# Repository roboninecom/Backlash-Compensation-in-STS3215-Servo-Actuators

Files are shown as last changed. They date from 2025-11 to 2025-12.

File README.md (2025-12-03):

# Backlash Compensation in STS3215 Servo Actuators

This repository contains the source code, data analysis scripts, and LaTeX source for the research paper **"Backlash Compensation in STS3215 Servo Actuators"**.

The project demonstrates a practical method to eliminate mechanical backlash in low-cost Feetech STS3215 servos using a dual-motor configuration with controlled pretension.

---

## 📂 Project Structure

```text
├── cad/                         # Hardware design files (.step and .stl)
├── logs/                        # Output directory for telemetry data (CSV)
├── paper/                       # LaTeX source code of the article and figures
├── software/
│   ├── backlash_test/
│   │   ├── .env                     # Environment variables
│   │   ├── .gitignore               # Git ignore rules
│   │   ├── app.js                   # Main Node.js controller application
│   │   ├── config.js                # Serial port configuration
│   │   ├── package.json             # Node.js dependencies and scripts
│   │   ├── sweepConfig.js           # Configuration for motion sequences
│   │   └── TelemetryLogger.js       # Module for CSV data logging
│   ├── logs_analysis/
│   │   ├── config/                  # Example config files
│   │   ├── log_calc.py              # Calculates backlash statistics based on provided CSV log file
│   |   ├── log_viz.py               # Generates visualisation from provided CSV log file
│   |   ├── config_utils.py          # Some common utilities used by analysis and visualisation scripts
```

## 🛠 Hardware Requirements

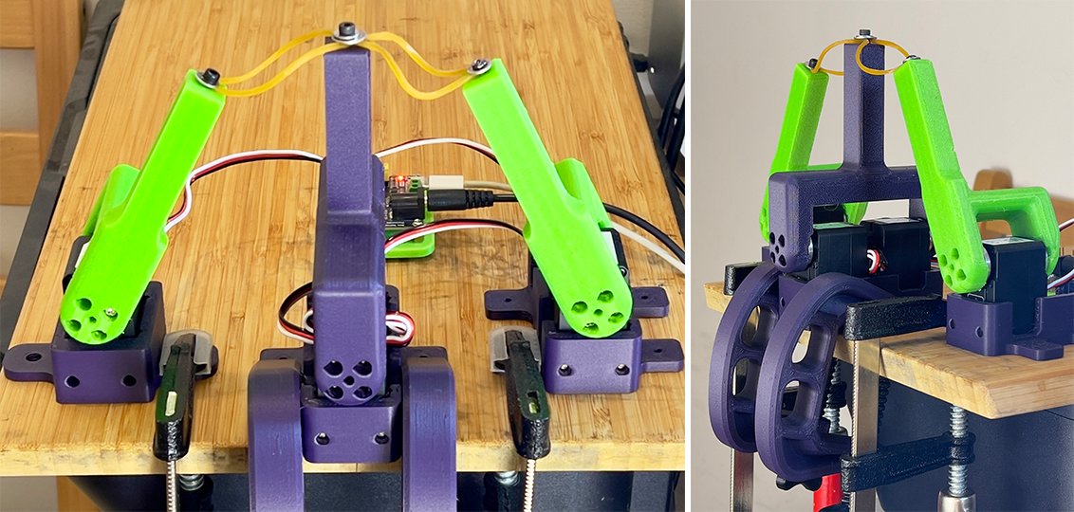
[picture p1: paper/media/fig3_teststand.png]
Test Stand Setup

*Figure: Mechanical test stand used for backlash measurements.*

To reproduce the experiments, you will need:
*   **Servos:** 2x Feetech STS3215 (configured in dual-mode) + additional servos for load testing.
*   **Controller:** USB-TTL Adapter (e.g., Feetech URT-1) connected to a PC.
*   **Power Supply:** 12V DC power supply capable of at least 3A.
*   **Mechanical Assembly:** Dual-servo bracket (see paper for details).

## 🚀 Getting Started

### 1. Controller Setup (Node.js)

The Node.js application manages the servos, executes motion profiles, and logs telemetry.

**Prerequisites:** Node.js (v14+), NPM.

```bash
cd software/backlash_test

# Install dependencies
npm install

# Configure environment variables
# Create a .env file or set these manually
export SERIAL_PORT=COM3           # Or /dev/ttyUSB0 on Linux/Mac
export SERIAL_BAUD_RATE=1000000
```

**Running the Experiment:**

To start the control loop and logging:

```bash
node app.js
```

*   Configuration for motion patterns and servo IDs is located in `sweepConfig.js`.
*   Logs are automatically saved to the `logs/` directory.

### 2. Motor analysis utilities

**Prerequisites:** Python 3.8+, pandas, matplotlib, numpy.

`log_calc.py` handles motor-analysis scenario by reading a JSON configuration that describes which motors define the analysis phase window, which motors should be reported, and the stretched/relaxed targets for the actuated motors. 

Run the script by passing the config and the log CSV:

```bash
python logs_analysis/log_calc.py logs_analysis/config/config_m1_m2.json /path/to/log.csv
```

`log_viz.py` uses the exact same config files to decide which motors to plot (from `report_motor_ids`) and which actuators provide the relaxed/stretched overlays. Invoke it the same way:

```bash
python logs_analysis/log_viz.py logs_analysis/config/config_m1_m2.json  /path/to/log.csv
```

## 📄 Research Paper

The full text of the research paper is located in the `paper/` directory.
You can compile it using any standard LaTeX distribution (TeX Live, MiKTeX) or online editor (Overleaf).

## 👥 Author Information

**Boris Kotov**
*   Senior Software Engineer, Robotics Control Systems.
*   Email: [hello@robonine.com](mailto:hello@robonine.com)

**Company: Robonine**
*   Developing accessible robotic solutions for education and research.
*   Website: [robonine.com](https://robonine.com)

## 📜 License

This project and the associated paper are distributed under the **Creative Commons Attribution 4.0 International License (CC BY 4.0)**.
You are free to share and adapt the material as long as appropriate credit is given.

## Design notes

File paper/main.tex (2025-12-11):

\documentclass[11pt,a4paper]{article}

\usepackage[margin=1in]{geometry}
\usepackage{graphicx}
\usepackage{amsmath,amssymb}
\usepackage{siunitx}
\sisetup{per-mode=symbol}
\usepackage{booktabs}
\usepackage{hyperref}
\usepackage{xurl}
\usepackage{caption}
\usepackage{placeins}

\title{Backlash Compensation in STS3215 Servo Actuators}
\author{Boris Kotov\\
Robonine\\
\texttt{boris.k@robonine.com}\\
\url{https://robonine.com}}
\date{}

\begin{document}
\maketitle

\begin{abstract}
This work presents a practical backlash compensation method for Feetech STS3215 servo actuators using a dual-motor configuration with controlled pretension. Experimental results show a reduction of effective output backlash from 14.78 encoder counts (approximately \SI{1.30}{\degree}) to 1--2 counts (approximately \SIrange{0.09}{0.18}{\degree}), approaching encoder resolution limits. The method does not require mechanical modification and maintains approximately \SI{80}{\percent} of total torque capacity. The technique is suitable for low-cost robotics and educational motion control systems.
\end{abstract}

\noindent\textbf{Keywords:} servo actuators, backlash compensation, dual motor drive, robotics, low-cost motion control

\vspace{0.5em}
\noindent\textbf{License.} This paper is distributed under the terms of the Creative Commons Attribution 4.0 International License (CC BY 4.0).

\section{Introduction}

The Feetech STS3215 servo has become popular in hobbyist and educational robotics due to its low cost, satisfactory torque output, integrated closed-loop controller, and straightforward serial interface. These characteristics make it attractive for student projects, DIY robotic arms, small mobile manipulators, pan--tilt units, gimbal mechanisms, and general-purpose articulated prototypes where inexpensive but reasonably precise actuation is needed. In such contexts, the STS3215 offers an accessible platform for experimenting with kinematics, feedback control, and embedded motion systems without the cost barriers of industrial-grade actuators.

Despite these advantages, the actuator exhibits several limitations. Because of its multi-stage gear train, total mechanical backlash is significant: measurements indicate approximately \SIrange{0.8}{0.9}{\degree} of rotational free play, corresponding to roughly \SI{1.3}{\milli\meter} of motion at a \SI{100}{\milli\meter} lever arm. This level of lost motion degrades positioning accuracy, complicates bidirectional tracking, and limits the usability of the servos in applications requiring precise reversals or high-fidelity control.

The goal of this study is to evaluate simple, implementable methods for reducing the functional impact of backlash when using a paired configuration of STS3215 servos. The work focuses on practical compensation strategies suitable for low-cost robotic systems, with the aim of improving motion accuracy without hardware modification.

\section{STS3215 Main Features}

\subsection{Hardware Specifications}

The main hardware specifications of the STS3215 servo are summarized in Table~\ref{tab:specs}.

\begin{table}[ht]
    \centering
    \caption{STS3215 main hardware specifications.}
    \label{tab:specs}
    \begin{tabular}{ll}
        \toprule
        Specification & Value \\
        \midrule
        Operating (nominal) voltage & \SI{12}{\volt} (operating range \SIrange{4}{14}{\volt}) \\
        Rated torque & \SI{10}{\kilo\gram\centi\meter} @ \SI{12}{\volt} \\
        Stall (peak) torque & \SI{30}{\kilo\gram\centi\meter} @ \SI{12}{\volt} \\
        Encoder resolution & 12-bit magnetic encoder: 4096 steps over \SI{360}{\degree} \\
        Gear type & Metal gearbox; steel gears and ball bearings \\
        Gear ratio & 1\,:\,345 reduction (12~V, 30~kg\,cm version) \\
        \bottomrule
    \end{tabular}
\end{table}

\subsection{Communication Architecture}

The STS3215 uses a half-duplex TTL serial bus, allowing multiple servos to share the same communication line. Servos can be daisy-chained by connecting their signal ports in series. All communication uses the manufacturer's digital packet protocol, which supports variable-length instruction and status frames.

The communication protocol supports synchronized actuation of multiple servos on the same bus. Through broadcast or group commands, several servos can receive and execute target updates simultaneously. This capability is essential for coordinated motion, such as paired joint actuation, dual-motor couplings, or experimental setups where timing symmetry between actuators directly affects performance.

\subsection{Device Identification and Memory}

Each servo contains a unique ID stored in EEPROM. EEPROM parameters are non-volatile and remain stored after power cycles. RAM parameters (e.g., present position, speed, voltage) reset at each boot.

\subsection{Main Control Modes}

The internal controller supports several operating modes:
\begin{enumerate}
    \item \textbf{Position control mode:} target position specified in encoder units; configurable speed and acceleration; supports continuous update of the goal position for trajectory tracking.
    \item \textbf{Continuous rotation / speed mode:} servo behaves like a motor with speed command, useful for wheels and drive systems.
\end{enumerate}

\subsection{Adjustable Parameters}

The internal controller exposes a set of parameters that influence performance and safety:
\begin{itemize}
    \item PID gains (proportional, integral, derivative), which shape servo stiffness, tracking accuracy, and damping.
    \item Deadband width around the target position; reducing the deadband increases accuracy but may increase oscillation.
    \item Speed and acceleration limits, including soft-start ramps to prevent overshoot and reduce gear stress.
    \item Protection options: over-voltage, under-voltage, over-temperature shutdown, over-current/overload protection, torque limit.
    \item Range and calibration settings: mechanical limits, angle offsets, and zero-position calibration using encoder feedback.
\end{itemize}

\subsection{Feedback and Status Reporting}

The servo provides live telemetry including present position (encoder units), speed, load estimate (proportional to current), supply voltage, temperature, and error flags (overload, overheating, voltage error, etc.).

\section{Backlash Compensation with Two Opposed STS3215 Servos}

\subsection{Mechanical Arrangement}

Two STS3215 servos are mounted back-to-back with their output shafts facing opposite directions. The shafts are mechanically coupled using the standard 25T servo horns (the small stock circular output disks) and a 3D-printed bridging clamp bracket secured with four screws into the horns. This rigid connection ensures accurate shaft alignment and minimizes relative motion between the servos during operation. The two servos are fixed together on a common mounting plate, maintaining their relative orientation and spacing.

\begin{figure}[ht]
    \centering
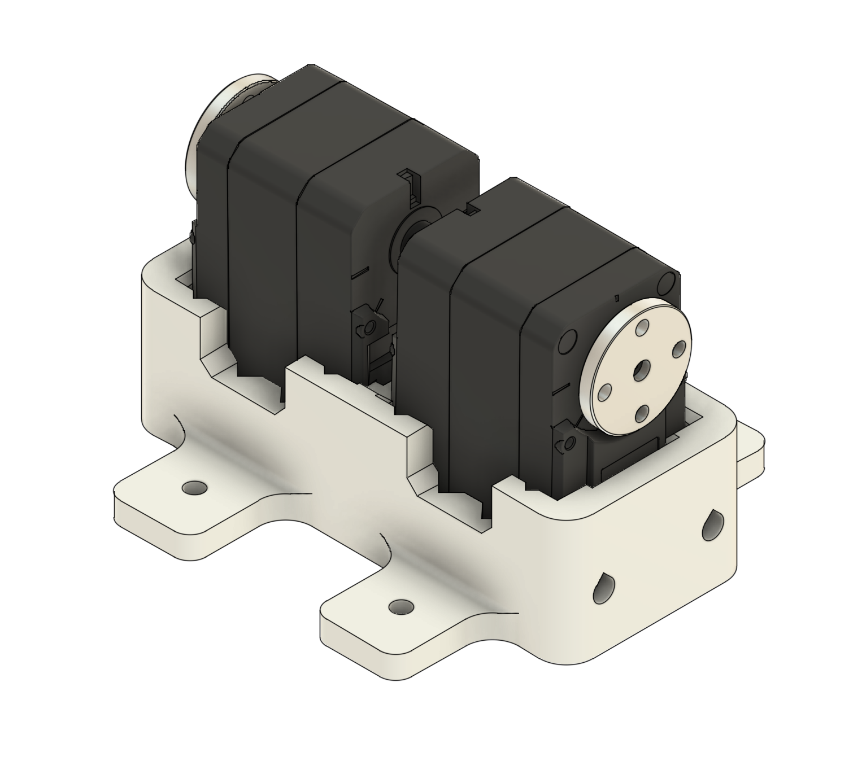
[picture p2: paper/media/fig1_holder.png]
    
    \caption{Two STS3215 servos mounted in the holder.}
    \label{fig:holder}
\end{figure}

\begin{figure}[ht]
    \centering
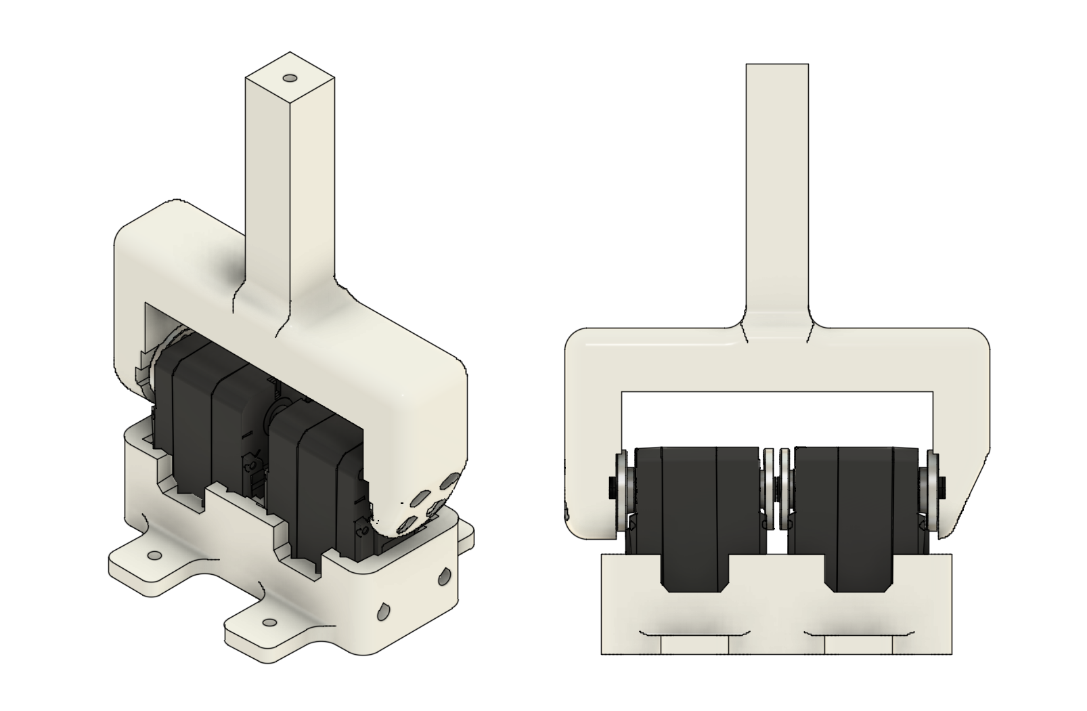
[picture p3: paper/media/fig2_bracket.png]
    
    \caption{Two STS3215 servos with attached test bracket and lever.}
    \label{fig:bracket}
\end{figure}

\subsection{Control Strategy}

Each STS3215 has finite gearbox backlash. When a single motor is commanded to change direction, the output shaft can move a small amount with minimal restoring torque as the gear teeth transition between flanks. By coupling two motors and biasing them in opposite directions, each motor keeps its gear train loaded on a different flank. The two dead zones no longer overlap, so the combined system exhibits near-zero play around the commanded angle.

We create that bias by giving the two motors slightly different home positions (a small position offset). At steady state, each motor holds a small position error, producing a steady pretension torque in opposite directions. In this work, the pretension is set to approximately \SI{3}{\percent} of stall torque---enough to take up the slack, but small enough to keep current and heat modest.

\subsection{Simple Model}

Let each motor have a backlash half-width $b$ (in encoder counts), so a single motor has an effective deadzone
\[
[-b, +b].
\]
Inside this zone, small changes of commanded position $u$ produce negligible output torque $T$:
\[
u \in [-b, b] \;\Rightarrow\; T \approx 0.
\]

When two motors are rigidly coupled and we apply an offset $d$ (counts) between their commanded angles, the steady-state torques $T_1$ and $T_2$ pull in opposite directions. If the magnitude of the offset is larger than the effective deadband,
\[
|d| > b_{\mathrm{eff}},
\]
where $b_{\mathrm{eff}}$ includes the controller deadband and mechanical play, both gear trains remain seated on opposite flanks. The combined closed-loop stiffness around the setpoint becomes approximately the sum of the individual stiffnesses, and the apparent deadzone collapses.

A practical rule from this setup is to choose $|d|$ slightly greater than the deadband but small enough that the resulting holding current remains modest. In our tests, an offset $d$ corresponding to roughly \SI{3}{\percent} of stall torque (about \SI{0.9}{\kilo\gram\centi\meter} for a \SI{30}{\kilo\gram\centi\meter} servo) worked well. On a \SI{100}{\milli\meter} lever, this torque corresponds to approximately \SI{0.09}{\kilo\gram force} at the tip (about \SI{0.88}{\newton}), which is enough to seat the gears without stressing the motor.

\subsection{Implementation Steps}

\begin{enumerate}
    \item Zero both motors mechanically (lever centered), with no offsets.
    \item Preload one flank: gently rotate the lever clockwise and set Motor~1's home position.
    \item Preload the opposite flank: gently rotate counter-clockwise and set Motor~2's home/offset so that Motor~2 pushes the other way.
    \item Verify current draw at rest and during small dithers; trim the offsets to target approximately \SI{3}{\percent} stall torque (or another chosen limit).
\end{enumerate}

\section{Test Setup and Limitations}

\subsection{Encoder Placement and Backlash Measurement}

The STS3215 incorporates its magnetic encoder after the gearbox, directly on the output shaft. This architecture simplifies control but introduces a measurement constraint: the encoder cannot observe motion within the internal gear stages. As a result, true internal backlash cannot be directly measured, because the internal PID loop continuously attempts to drive the shaft to the commanded position.

Within the default deadband range, however, the controller does not correct small deviations, allowing the output shaft to move freely inside the mechanical slack. This characteristic enables an indirect measurement method. When torque is enabled and a small external force is applied to the output lever, the encoder reading changes even though the controller remains within its deadband. Knowing the encoder resolution, these small deviations can be converted into angular displacement, providing an estimate of effective backlash.

\subsection{Test Stand}

A simple mechanical test stand was constructed to evaluate backlash and the effectiveness of compensation methods. The setup consists of:
\begin{enumerate}
    \item \textbf{Primary test motor(s):} one or two STS3215 servos serving as the unit under test. A rigid \SI{100}{\milli\meter} lever is mounted to the output shaft to amplify measurable motion.
    \item \textbf{Opposing actuation motors:} two additional STS3215 units, each equipped with its own lever, are mounted opposite the primary lever. These ``puller'' motors apply controlled forces in clockwise and counter-clockwise directions to displace the primary shaft within its backlash zone.
\end{enumerate}

\begin{figure}[ht]
    \centering
    
    \caption{Mechanical test stand used for backlash measurements.}
    \label{fig:teststand}
\end{figure}

\subsection{Opposing-Load Mechanism (Elastic Bands)}

To apply a controlled, repeatable counter-torque without introducing extra drivetrain backlash, the two opposing motors pull the main \SI{100}{\milli\meter} lever via elastic bands. The bands are pre-tensioned so that the measured pull at the lever tip is approximately \SI{0.3}{\kilo\gram force}.

The resulting torque at the lever tip is
\[
\tau \approx 0.3~\text{kgf} \times 0.1~\text{m} \approx \SI{0.294}{\newton\meter} \approx \SI{3.0}{\kilo\gram\centi\meter},
\]
which is about \SI{10}{\percent} of stall torque (\SI{30}{\kilo\gram\centi\meter}) and \SI{30}{\percent} of rated torque (\SI{10}{\kilo\gram\centi\meter}) for a single STS3215 at \SI{12}{\volt}. This is high enough to fully seat the gear train in either direction, yet low enough to avoid saturating the internal controller.

The elastic coupling provides a compliant, backlash-free load path, so backlash in the two opposing motors can be ignored. It also smooths load reversals, reducing shock and motor current spikes during the back-and-forth sequence.

\begin{figure}[ht]
    \centering
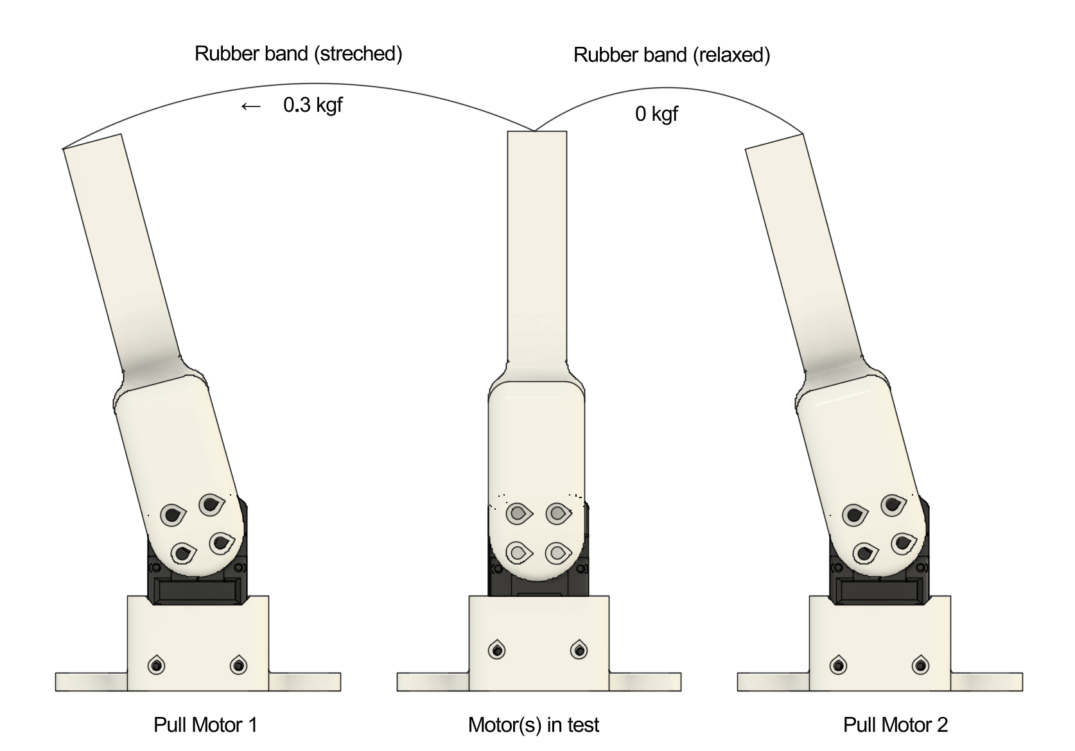
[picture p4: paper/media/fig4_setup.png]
    
    \caption{Example test setup. The center motor holds position while the left puller motor applies approximately \SI{0.3}{\kilo\gram force} to the lever. The right puller motor is relaxed and does not apply force.}
    \label{fig:setup}
\end{figure}

\subsection{Force Application Sequence}

The primary motor executes a short back-and-forth movement to preload its internal gears in either the clockwise or counter-clockwise direction. Once loaded, the opposing motors alternately pull the lever in opposite directions. Between pulls, they briefly release tension to ensure that no residual force biases the measurement. The entire sequence---preload motions, alternating pulls, and release intervals---is coordinated by custom control code running on the host controller.

\begin{figure}[ht]
    \centering
    
    \caption{Test sequence, stage~1 (preparation). Both elastic bands are relaxed. The tested motor(s) move in CW or CCW direction and return to the center position, preloading the gears.}
    \label{fig:sequence1}
\end{figure}

\begin{figure}[ht]
    \centering
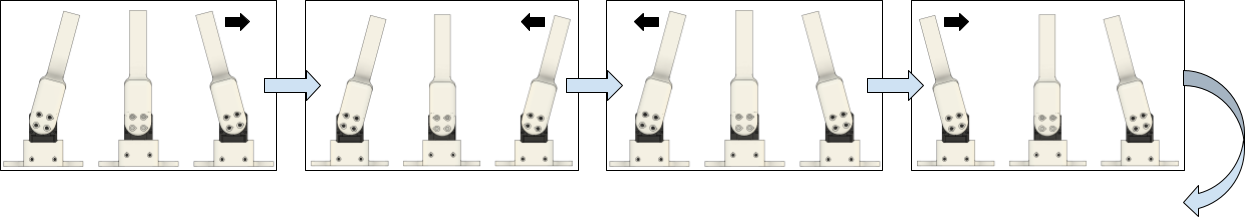
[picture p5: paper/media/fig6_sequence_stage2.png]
    
    \caption{Test sequence, stage~2 (stress). The lever of the tested motor(s) remains in the central position while the pull motors alternately apply load in opposite directions. Between pulls, both elastic bands are relaxed.}
    \label{fig:sequence2}
\end{figure}

\subsection{Telemetry Acquisition}

All servos stream periodic status data to the host, where custom logging software collects and stores it in CSV format for later analysis. Logged parameters include:
\begin{itemize}
    \item timestamp,
    \item present and target positions,
    \item load/torque estimate and current consumption.
\end{itemize}
A Python post-processing script visualizes the motion profiles and computes effective backlash by analyzing position deviations caused by the alternating external forces.

\subsection{Limitations}

Several limitations should be noted:
\begin{itemize}
    \item Because the encoder is placed after the gearbox, only output backlash can be observed; internal gear-stage behavior remains unmeasured.
    \item The internal PID deadband interacts with the measurement method: too small a deadband causes the controller to fight the applied force, whereas too large a deadband reduces measurement resolution. The default deadband setting is used here.
    \item Over the small displacements used for backlash probing, elastic band force change is minimal but not zero, introducing a small nonlinearity.
\end{itemize}

\section{Results and Analysis}

\subsection{Quantities and Conversions}

With a 12-bit encoder, one revolution corresponds to 4096 counts, so one count is
\[
\Delta \theta = \frac{360^\circ}{4096} \approx 0.0879^\circ.
\]
At a radius of \SI{100}{\milli\meter}, the corresponding linear displacement per count is
\[
\Delta x \approx 0.0879^\circ \times \frac{\pi}{180^\circ} \times 100~\text{mm} \approx \SI{0.153}{\milli\meter}.
\]

\subsection{Backlash Measurement Procedure}

As part of each test, a sequence of motions is executed according to the force application sequence described above. During this sequence, motor telemetry (including each servo current position and target position) is sampled at approximately \SI{10}{\hertz} rate. For each cycle, two reference conditions are extracted:
\begin{itemize}
    \item \textbf{Loaded reference:} the actual encoder position while the pull motors apply a nominal \SI{0.3}{\kilo\gram force} to the lever in one direction.
    \item \textbf{Unloaded reference:} the actual encoder position immediately after both pull motors have relaxed and no external force is applied to the main lever.
\end{itemize}

For each pull direction (CW and CCW), two reference points are extracted from the telemetry stream:
\begin{itemize}
    \item \textbf{Unloaded (relaxed) state:} the actual encoder position immediately after both pull motors release tension.
    \item \textbf{Loaded (stretched) state:} the actual encoder position while the approximately \SI{0.3}{\kilo\gram force} is applied in that direction.
\end{itemize}

For each of these states, multiple samples are collected over the repeated motion cycles. The samples are averaged to obtain stable estimates of:
\begin{itemize}
    \item $p_{\mathrm{cw,unloaded}}$
    \item $p_{\mathrm{ccw,unloaded}}$
    \item $p_{\mathrm{cw,loaded}}$
    \item $p_{\mathrm{ccw,loaded}}$
\end{itemize}

The total positional deviation between the two pull directions is then computed separately for the unloaded and loaded conditions:
\begin{align}
d_{\mathrm{unloaded}} &= \bigl| p_{\mathrm{cw,unloaded}} - p_{\mathrm{ccw,unloaded}} \bigr|, \\
d_{\mathrm{loaded}} &= \bigl| p_{\mathrm{cw,loaded}} - p_{\mathrm{ccw,loaded}} \bigr|.
\end{align}

These two values represent the measured backlash in the absence of external force and under the applied counter-torque, respectively. Since the motion sequence is repeated multiple times, a sufficient number of samples is collected to compute the average backlash and its dispersion for each configuration (single motor, dual motor, dual motor with preload).

\subsection{Single STS3215 Servo with Default Settings}

Before evaluating dual-motor compensation methods, the backlash of a single STS3215 servo was measured to establish a baseline. The motor was mounted rigidly, driven to a fixed target position (2047 counts), and subjected to the standard force-application sequence.

\begin{figure}[ht]
    \centering
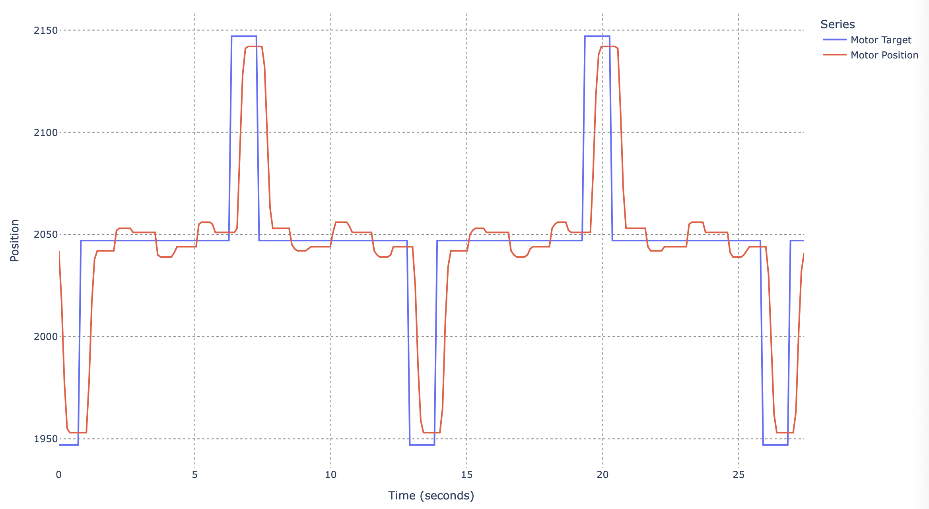
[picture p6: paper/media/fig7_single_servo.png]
    
    \caption{Test results for a single STS3215 servo with default settings under alternating external load.}
    \label{fig:single}
\end{figure}

For the single STS3215, the measured position deviation between CW and CCW loading was:
\begin{itemize}
    \item Loaded state: 14.78 counts,
    \item Unloaded (relaxed) state: 7.03 counts.
\end{itemize}
These correspond to:
\begin{itemize}
    \item Loaded backlash: $\approx \SI{1.30}{\degree}$ or $\approx \SI{2.27}{\milli\meter}$ at \SI{100}{\milli\meter} radius,
    \item Unloaded backlash: $\approx \SI{0.62}{\degree}$ or $\approx \SI{1.08}{\milli\meter}$ at \SI{100}{\milli\meter} radius.
\end{itemize}
These results confirm that a single STS3215 exhibits on the order of 1--2~mm of effective backlash at a \SI{100}{\milli\meter} lever radius, increasing under load.

\subsection{Coupled STS3215 Servos with Default Settings}

To evaluate the effect of mechanically coupling two STS3215 servos, the motors were first tested in a rigid back-to-back configuration without applying any positional offset or deliberate pretension. Both actuators were commanded to the same target position and driven synchronously, sharing a common output through the fixed bracket assembly.

\begin{figure}[ht]
    \centering
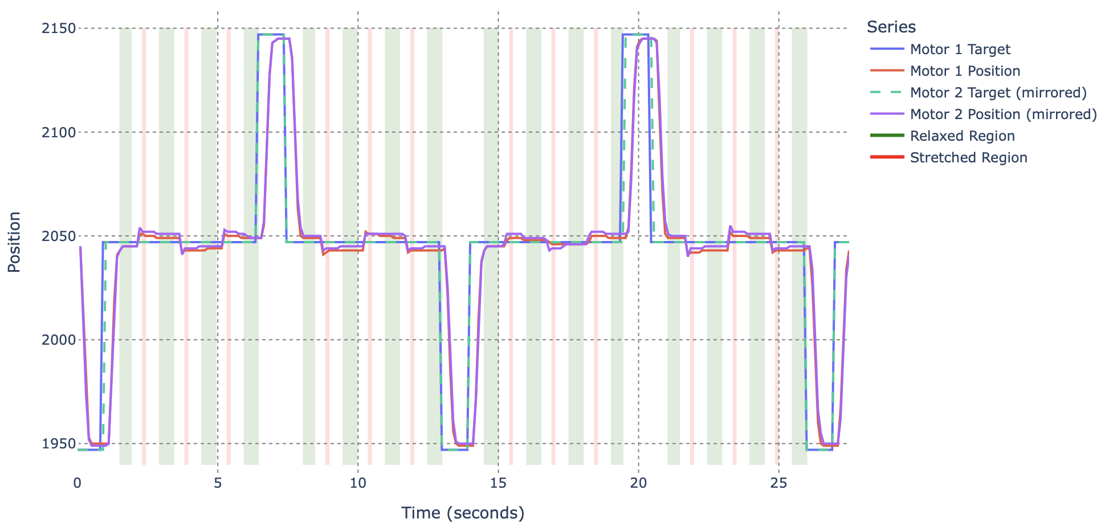
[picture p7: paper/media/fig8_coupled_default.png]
    
    \caption{Test results for two coupled STS3215 servos with default settings. Highlighted regions indicate intervals with relaxed and stretched elastic bands. Red and blue curves denote measured positions of Servo~1 and Servo~2; the dashed line shows the commanded target position.}
    \label{fig:coupled_default}
\end{figure}

With two STS3215 servos rigidly coupled and commanded to the same target position, the effective backlash is reduced compared to a single actuator. From the averaged data, the total position deviation between CW and CCW loading is:

\textbf{Loaded} (approximately \SI{3}{\kilo\gram\centi\meter}):
\begin{itemize}
    \item Servo~1: 7.50 counts $\approx \SI{0.66}{\degree} \approx \SI{1.15}{\milli\meter}$ at \SI{100}{\milli\meter} radius,
    \item Servo~2: 8.00 counts $\approx \SI{0.70}{\degree} \approx \SI{1.23}{\milli\meter}$ at \SI{100}{\milli\meter} radius.
\end{itemize}

\textbf{Unloaded:}
\begin{itemize}
    \item Servo~1: 6.00 counts $\approx \SI{0.53}{\degree} \approx \SI{0.92}{\milli\meter}$,
    \item Servo~2: 6.00 counts $\approx \SI{0.53}{\degree} \approx \SI{0.92}{\milli\meter}$.
\end{itemize}

Simply coupling two STS3215s back-to-back approximately halves the loaded backlash compared to the single-motor case, even before applying explicit compensation.

\subsection{Coupled STS3215 Servos with Home Position Offset}

To further reduce residual backlash, a controlled home-position offset was introduced between the two coupled STS3215 units. The lever assembly was manually rotated to preload the gear train of one motor in the CW direction, and this position was stored as its home reference. The lever was then rotated in the opposite direction to preload the second motor in CCW, and its home position was recorded accordingly. This procedure establishes a small, constant pretension torque between the servos, ensuring that both gear trains remain seated on opposite flanks.

\begin{figure}[ht]
    \centering
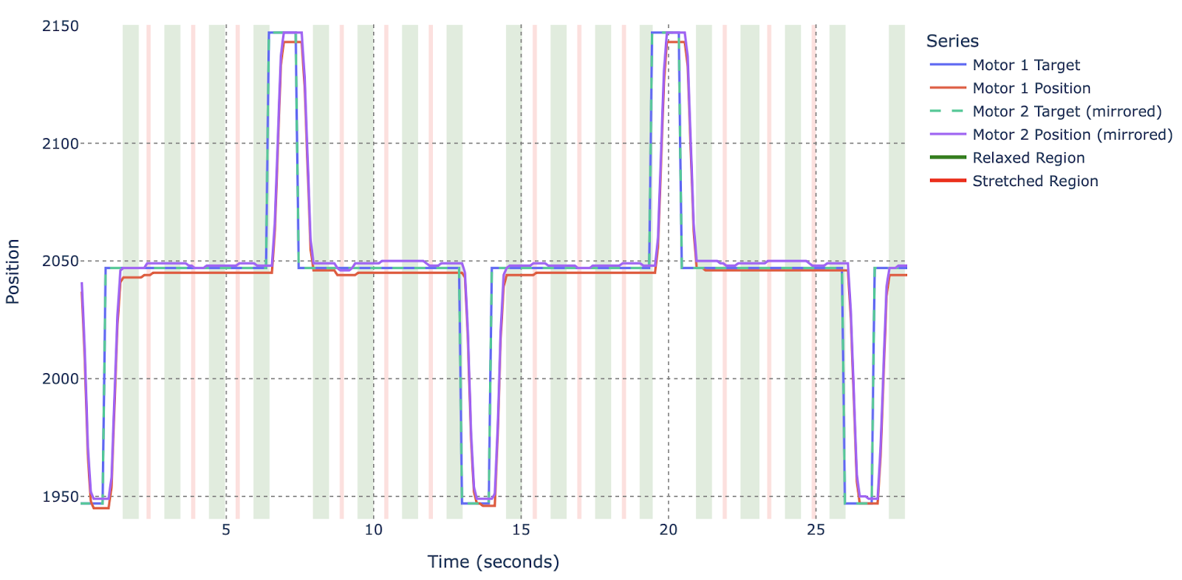
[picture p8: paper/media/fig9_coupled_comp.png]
    
    \caption{Test results for two coupled STS3215 servos with backlash compensation via home-position offset. Red and blue curves denote Servo~1 and Servo~2; the dashed line shows the commanded position. Highlighted regions indicate relaxed and stretched load intervals.}
    \label{fig:coupled_comp}
\end{figure}

\begin{figure}[ht]
    \centering
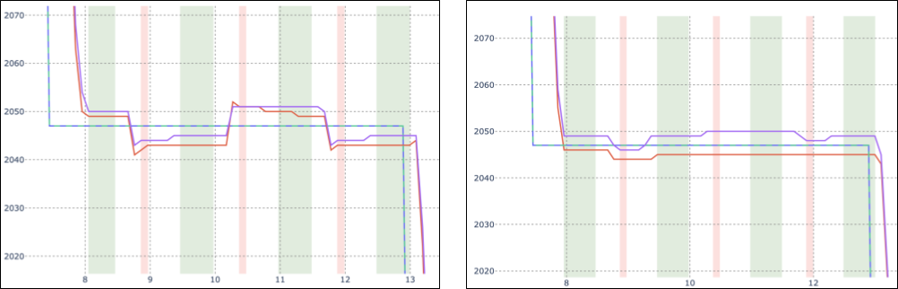
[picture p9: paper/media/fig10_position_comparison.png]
    
    \caption{Position deviation comparison for coupled servos. Left: configuration with default settings (no compensation). Right: configuration with home-position offset providing pretension.}
    \label{fig:comparison}
\end{figure}

With the home-position offset (pretension) applied, the measured position deviation is:

\textbf{Loaded} (approximately \SI{3}{\kilo\gram\centi\meter}):
\begin{itemize}
    \item Servo~1: 0 counts,
    \item Servo~2: 2 counts $\approx \SI{0.18}{\degree} \approx \SI{0.31}{\milli\meter}$ at \SI{100}{\milli\meter} radius.
\end{itemize}

\textbf{Unloaded:}
\begin{itemize}
    \item Servo~1: 0 counts,
    \item Servo~2: 1 count $\approx \SI{0.088}{\degree} \approx \SI{0.15}{\milli\meter}$ at \SI{100}{\milli\meter} radius.
\end{itemize}

With a small home-position offset that preloads the two servos against opposite gear flanks, the apparent backlash is reduced to 1--2 encoder counts, i.e., on the order of the encoder's own resolution (approximately \SIrange{0.09}{0.18}{\degree}, \SIrange{0.15}{0.31}{\milli\meter} at \SI{100}{\milli\meter} radius). This is a very significant improvement over the single-motor case and a clear improvement over the uncompensated dual-motor configuration.

\FloatBarrier

\subsection{Results Summary}

To enable direct comparison among all test configurations, backlash values for both loaded (L) and unloaded (U) conditions were compiled into a single results table. For dual-motor setups, the larger (worst-case) deviation between the two servos is used to represent system backlash.

\begin{table}[ht]
    \centering
    \caption{Combined backlash test results. U: unloaded (measured immediately after both pulling motors relax). L: loaded (measured while the \SI{0.3}{\kilo\gram force} counter-force is applied). Backlash is expressed in encoder counts, angular displacement, and linear displacement at a \SI{100}{\milli\meter} radius. For two-motor setups, the larger of the two measured deviations is reported.}
    \label{tab:backlash}
    \begin{tabular}{lccc}
        \toprule
        Configuration & Backlash (counts) & Backlash (deg) & Backlash (mm) \\
        \midrule
        Single motor (U) & 7.03 & 0.62 & 1.07 \\
        Single motor (L) & 14.78 & 1.30 & 2.26 \\
        Coupled, no compensation (U) & 6.00 & 0.53 & 0.92 \\
        Coupled, no compensation (L) & 8.00 & 0.70 & 1.22 \\
        Coupled, offset compensation (U) & 1.00 & 0.09 & 0.15 \\
        Coupled, offset compensation (L) & 2.00 & 0.18 & 0.31 \\
        \bottomrule
    \end{tabular}
\end{table}

\FloatBarrier

\section{Conclusions}

The experiments confirm that mechanical backlash in STS3215 servos can be effectively minimized through a dual-actuator configuration. By coupling two motors and introducing a small positional offset, both gear trains remain preloaded against opposite flanks, effectively eliminating the free-motion zone. The resulting system maintains approximately \SI{80}{\percent} of the combined torque capacity of both servos, indicating only minor efficiency losses while achieving near-zero measurable backlash.

Thermal monitoring showed no overheating or abnormal current draw, suggesting that the applied pretension remains within safe limits for continuous operation. This simple, low-cost compensation method significantly improves positioning accuracy and rigidity using standard hobby-grade components, making it well suited for robotics studies, educational applications, and precision motion experiments.

\section{Future Work}

Future work may include dynamic backlash compensation, where the pretension or position offset is adjusted in real time based on torque feedback or direction of motion. It would also be valuable to study the influence of mechanical coupling stiffness, including bracket material and geometry, on system behavior.

Additional tests with different servo models, gear ratios, and control tunings could help generalize the method and quantify its limits in higher-load or high-speed applications.

\section*{Appendix: Code and Supplementary Materials}

Custom control code for the dual-servo compensation system, mechanical design files (CAD models), test stand schematics, and post-processing scripts are available at:

\noindent GitHub repository: \url{https://github.com/roboninecom/Measuring-Backlash-in-Popular-UART-Servos}

\section*{Author Information}

\textbf{Boris Kotov} is a senior software engineer specializing in robotics control systems and embedded programming for autonomous platforms.

\textbf{Robonine} is a company focused on developing accessible robotic solutions for education and research (\url{https://robonine.com}).

\nocite{*}
\bibliographystyle{ieeetr}
\bibliography{references}

\end{document}

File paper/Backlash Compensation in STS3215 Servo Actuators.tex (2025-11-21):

\documentclass[11pt,a4paper]{article}

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

\title{Backlash Compensation in STS3215 Servo Actuators}
\author{Boris Kotov\\
Robonine\\
\texttt{hello@robonine.com}\\
\url{https://robonine.com}}
\date{}

\begin{document}
\maketitle

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

\noindent\textbf{Keywords:} servo actuators, backlash compensation, dual motor drive, robotics, low-cost motion control

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

\section{Introduction}

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

\section{STS3215 Main Features}

\subsection{Hardware Specifications}

The main hardware specifications of the STS3215 servo are summarized in Table~\ref{tab:specs}.

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

\subsection{Communication Architecture}

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

\subsection{Device Identification and Memory}

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

\subsection{Main Control Modes}

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

\subsection{Adjustable Parameters}

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

\subsection{Feedback and Status Reporting}

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

\section{Backlash Compensation with Two Opposed STS3215 Servos}

\subsection{Mechanical Arrangement}

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

\subsection{Control Strategy}

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

\subsection{Simple Model}

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

\subsection{Implementation Steps}

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

\section{Test Setup and Limitations}

\subsection{Encoder Placement and Backlash Measurement}

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

\subsection{Test Stand}

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

\subsection{Opposing-Load Mechanism (Elastic Bands)}

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

\subsection{Force Application Sequence}

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

\subsection{Telemetry Acquisition}

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

\subsection{Limitations}

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

\section{Results and Analysis}

\subsection{Quantities and Conversions}

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

\subsection{Backlash Measurement Procedure}

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

\subsection{Single STS3215 Servo with Default Settings}

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

\subsection{Coupled STS3215 Servos with Default Settings}

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

\subsection{Coupled STS3215 Servos with Home Position Offset}

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

With the home-position offset (pretension) applied, the measured position deviation is:

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

\subsection{Results Summary}

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

\section{Conclusions}

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

\section{Future Work}

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

\section*{Appendix: Code and Supplementary Materials}

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

\noindent GitHub repository: \url{https://github.com/roboninecom/Backlash-Compensation-in-STS3215-Servo-Actuators}

\section*{Author Information}

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

\begin{thebibliography}{9}

\bibitem{feetech_manual}
Feetech Automatic Technology Co., Ltd., ``STS3215 Serial Bus Servo User Manual,'' 2023. Available at \url{https://wiki.feetech.com/en/wiki/STS3215} (accessed: 20 Nov. 2025).

\bibitem{tao_backlash}
G.~Tao and P.~V.~Kokotovic, ``Adaptive Control of Systems with Backlash,'' \emph{Automatica}, vol.~29, no.~2, pp.~323--335, 1993, doi:~10.1016/0005-1098(93)90126-E.

\bibitem{nordin_survey}
M.~Nordin and P.~O.~Gutman, ``Controlling Mechanical Systems with Backlash---A Survey,'' \emph{Automatica}, vol.~38, no.~10, pp.~1633--1649, 2002, doi:~10.1016/S0005-1098(02)00047-X.

\bibitem{chandrasekar_measurement}
S.~Chandrasekar and K.~Srinivasan, ``Inferential Based Measurement of Backlash in Servo System,'' \emph{International Journal of Mechanical Sciences}, vol.~175, p.~105505, 2020, doi:~10.1016/j.ijmecsci.2020.105505.

\bibitem{hou_dual_motor}
L.~Hou, Y.~Cao, X.~Li, M.~Gao, and S.~Wang, ``Backlash Elimination Control for Robotic Joints with Dual-Motor Drive,'' \emph{Actuators}, vol.~13, no.~8, p.~291, 2024, doi:~10.3390/act13080291.

\bibitem{tan_precision}
J.~Tan, N.~Zhang, Y.~Zhao, and Z.~Wang, ``Nonlinear Robust Adaptive Precision Motion Control of Motor Servo Systems with Unknown Actuator Backlash Compensation,'' \emph{ISA Transactions}, vol.~138, pp.~237--251, 2023, doi:~10.1016/j.isatra.2023.02.022.

\bibitem{zhou_deadzone}
L.~Zhou, Z.~Mao, and J.~Huang, ``Robust Stabilization of Nonlinear Uncertain Plants with Backlash or Dead Zone in the Actuator,'' \emph{IEEE Transactions on Control Systems Technology}, vol.~10, no.~2, pp.~158--166, 2002, doi:~10.1109/87.987060.

\end{thebibliography}

\end{document}

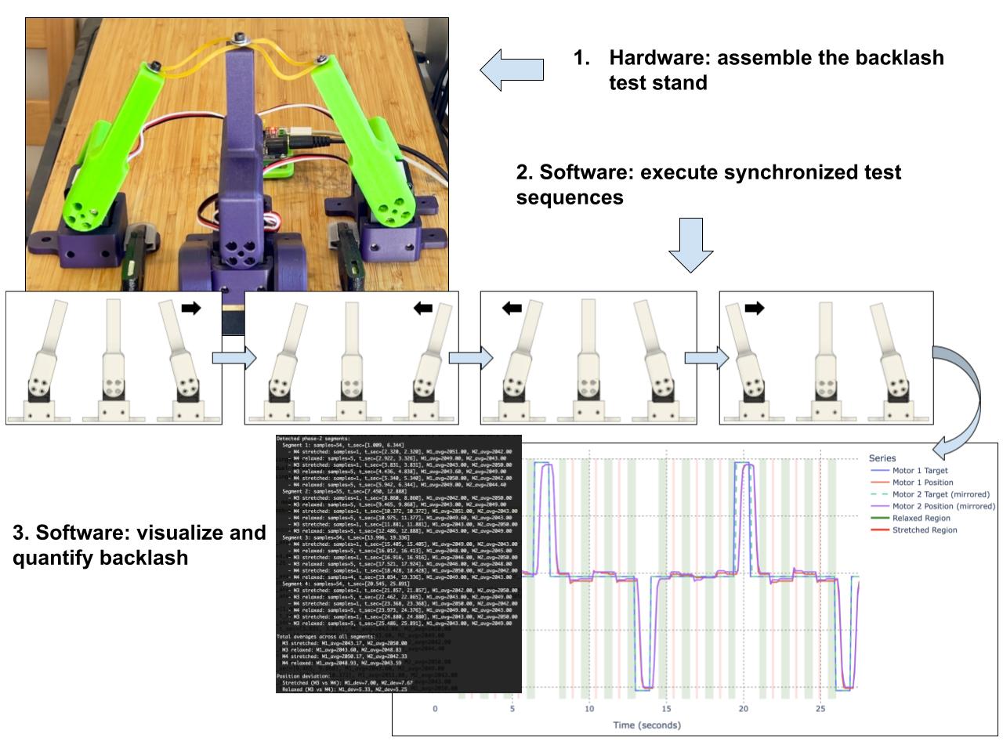
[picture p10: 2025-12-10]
paper/media_stand/graphical_abstract.jpg

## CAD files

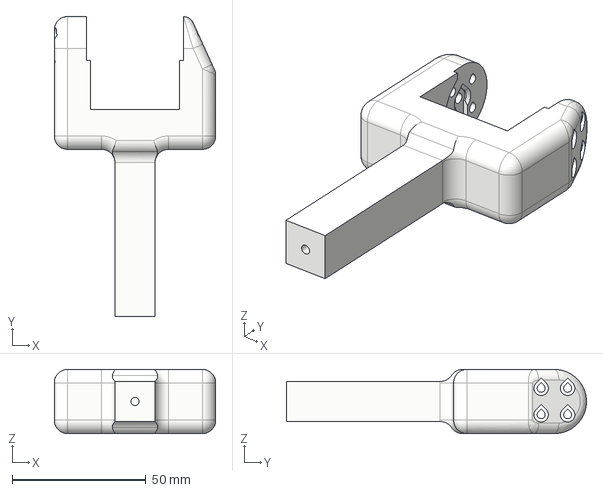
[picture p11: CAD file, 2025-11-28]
cad/test_lever_100mm_single.step
60.4 x 112.2 x 24.0 mm

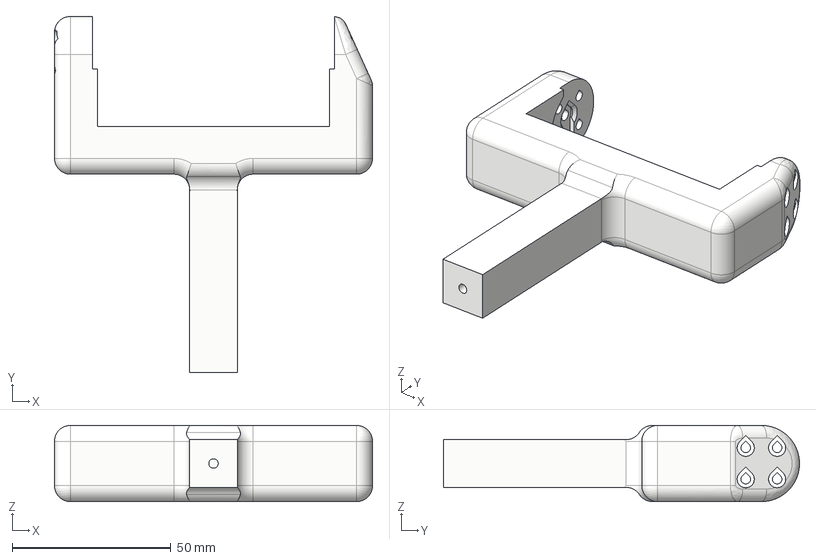
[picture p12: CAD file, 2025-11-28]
cad/test_lever_100mm_dual.step
100.2 x 112.2 x 24.0 mm

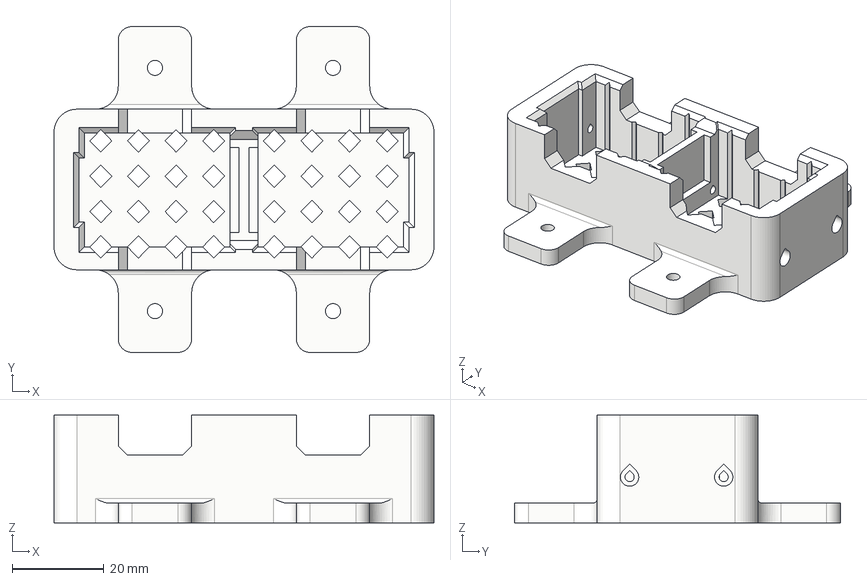
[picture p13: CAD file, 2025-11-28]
cad/servo_holder_dual.step
82.8 x 71.0 x 23.5 mm

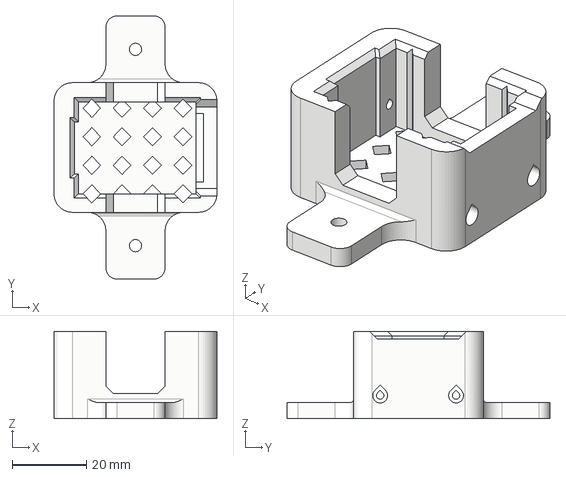
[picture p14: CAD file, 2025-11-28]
cad/servo_holder_single.step
44.0 x 71.0 x 23.5 mm

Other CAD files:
cad/servo_holder_dual.stl
cad/servo_holder_single.stl
cad/test_lever_100mm_dual.stl
cad/test_lever_100mm_single.stl

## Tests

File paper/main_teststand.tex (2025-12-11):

\documentclass[11pt,letterpaper]{article}

\usepackage[utf8]{inputenc}

\usepackage[margin=1.5cm]{geometry}
\usepackage{graphicx}
\usepackage{amsmath,amssymb}
\usepackage{siunitx}
\sisetup{per-mode=symbol}
\usepackage{booktabs}
\usepackage{hyperref}
\usepackage{xurl}
\usepackage{caption}
\usepackage{longtable}
\usepackage{array}
\usepackage{multirow}
\usepackage{float}
\usepackage{listings}
\usepackage{xcolor}
\usepackage{placeins}

\definecolor{codegray}{rgb}{0.5,0.5,0.5}
\definecolor{codegreen}{rgb}{0,0.6,0}
\definecolor{backcolour}{rgb}{0.95,0.95,0.92}

\lstdefinestyle{mystyle}{
    backgroundcolor=\color{backcolour},   
    commentstyle=\color{codegreen},
    keywordstyle=\color{magenta},
    numberstyle=\tiny\color{codegray},
    stringstyle=\color{purple},
    basicstyle=\ttfamily\footnotesize,
    breakatwhitespace=false,         
    breaklines=true,                 
    captionpos=b,                    
    keepspaces=true,                 
    numbers=left,                    
    numbersep=5pt,                  
    showspaces=false,                
    showstringspaces=false,
    showtabs=false,                  
    tabsize=2
}

\lstset{style=mystyle}

% HardwareX formatting
\newcolumntype{L}[1]{>{\raggedright\arraybackslash}p{#1}}
\newcolumntype{R}[1]{>{\raggedleft\arraybackslash}p{#1}}

\title{A Low-Cost Platform for Measuring Backlash in Popular UART Servos}
\author{Boris Kotov\textsuperscript{*}\\
Robonine\\
\texttt{boris.k@robonine.com}\\
\url{https://robonine.com}}
\date{}

\begin{document}
\maketitle

\begin{abstract}
Backlash in compact servo actuators is a common source of positioning error in low-cost robotic and mechatronic systems. Measuring this backlash reliably is difficult because most servos include only a single output-shaft encoder, and conventional tools such as dial indicators can introduce enough probing force to distort the measurement.

We present an open-source test stand that applies small, repeatable loads to a servo lever and measures the resulting displacement under both loaded and unloaded conditions. The stand uses low-cost components, 3D-printed fixtures, interchangeable levers, and a soft elastic coupling to apply controlled forces in opposite directions. Accompanying software coordinates the test sequence, records telemetry, and analyzes backlash using a consistent, repeatable methodology.

We demonstrate how the platform can characterize single-servo and coupled-servo configurations, enabling direct comparison of mechanical performance and aiding actuator selection in design work. All CAD files, control software, and analysis tools are openly provided to support replication and further development.
\end{abstract}

\noindent\textbf{Keywords:} open-source hardware; backlash measurement; servo actuators; test stand; gear characterization; robotics; low-cost instrumentation; non-contact measurement

\newpage
%==============================================================================
\section*{Specifications Table}
%==============================================================================

\begin{table}[H]
\centering
\begin{tabular}{ll}
\toprule
\textbf{Hardware name} & Servo Backlash Measurement Test Stand \\
\midrule
\textbf{Subject area} & 
\begin{minipage}[t]{10cm}
\begin{itemize}
    \item[$\bullet$] Engineering and material science
    \item[$\bullet$] Educational tools and open source alternatives to existing infrastructure
\end{itemize}
\end{minipage} \\
\midrule
\textbf{Hardware type} & 
\begin{minipage}[t]{10cm}
\begin{itemize}
    \item[$\bullet$] Mechanical engineering and materials science
\end{itemize}
\end{minipage} \\
\midrule
\textbf{Closest commercial analog} & \begin{minipage}[t]{10cm}Industrial gear measurement systems (Klingelnberg, Gleason, Mahr): \$3,500--\$100,000+; Double-flank gear rolling testers: \$750--\$16,500; Dial indicator setups: \$50--\$200. No direct low-cost commercial analog exists for automated servo actuator backlash measurement with zero probe contact force.\end{minipage} \\
\midrule
\textbf{Open source license} & 
\begin{minipage}[t]{10cm}
Hardware: CERN Open Hardware Licence Version 2 -- Permissive (CERN-OHL-P-2.0)\\
Software: MIT License\\
Documentation: CC BY 4.0
\end{minipage} \\
\midrule
\textbf{Cost of hardware} & Approximately \$80--100 USD (complete test stand) \\
\midrule
\textbf{Source file repository} & \begin{minipage}[t]{10cm}DOI: [To be assigned upon Zenodo upload]\\
Zenodo: \url{https://zenodo.org/records/17901040}\\
(GitHub mirror: \url{https://github.com/roboninecom/Measuring-Backlash-in-Popular-UART-Servos})\end{minipage} \\
\bottomrule
\end{tabular}
\end{table}

%==============================================================================
\section{Hardware in Context}
\label{sec:hardware-context}
%==============================================================================

Low-cost servo motors have become a common choice in DIY robotics, hobby mechatronics, and education. UART-controlled servos—such as those from Feetech, Waveshare, and similar manufacturers—are especially popular because they offer digital configuration, compact size, and affordable pricing. Their simplicity makes them easy to integrate into small research setups and classroom projects.

Despite these advantages, such servos have important limitations. Most notably, their geartrains introduce mechanical backlash, creating a region where changes in the commanded position do not immediately move the output shaft. Even a small amount of backlash can reduce positioning accuracy, degrade repeatability, or lead to oscillatory behavior. In addition, these servos typically include only a single encoder on the output shaft, so internal gear motion cannot be observed directly and must instead be inferred from output behavior.

Backlash in small servos is often measured using a dial indicator at the lever tip. While convenient, this method introduces several sources of error. The indicator tip applies a small but non-negligible force, which can shift the output shaft and mask the true backlash. Friction in the indicator mechanism, inconsistent contact pressure, and difficulty keeping the lever aligned with the measurement axis add further uncertainty. In lightweight or compliant servos, the probing force may even be comparable to the internal holding torque, making readings unreliable.

 Dial-indicator-based and more advanced inferential and drive-side measurement techniques for backlash are discussed, for example, in \cite{backlash_measurement_methods,chandrasekar_measurement,yang_mcsa_backlash}.

Users often try to improve performance by tuning PID parameters, adjusting acceleration or speed limits, or coupling two servos together to create a preloaded system. Although these strategies can reduce effective backlash, it is difficult to evaluate them in a repeatable way. Because each servo runs its own internal control loop, the observed behavior always combines mechanical properties with firmware decisions. Small changes in load, torque, or controller settings can produce results that are hard to interpret without a controlled test environment.

 A broad range of control strategies for systems with backlash, including adaptive and robust schemes and dual-motor drive concepts, has been studied in the control literature \cite{tao_backlash,nordin_survey,yuan_precision,sun_dual_motor,corradini_backlash_deadzone}.

These limitations highlight the need for a method that can apply small, repeatable, and well-controlled forces, in both directions, without disturbing the internal drivetrain in uncontrolled ways.

To address this need, we developed an open-source test stand specifically for characterizing backlash and related behavior in UART servos. The stand uses inexpensive components—3D-printed structures, low-cost servos, elastic-band loading, and simple electronics—to create a controlled environment in which force, position, and motion sequences can be repeated reliably. A high-level overview of the hardware and software components is provided in Section~\ref{sec:hardware-description}.

The stand makes it possible to:

\begin{itemize}
    \item Apply calibrated forces in both clockwise and counter-clockwise directions
    \item Measure how the servo responds under load and no-load conditions
    \item Log detailed telemetry for offline analysis and visualization
\end{itemize}

\subsection{Hardware overview}
\label{subsec:hardware-overview}

The test stand consists of:
\begin{enumerate}
    \item \textbf{Loading system:} Two STS3215 puller motors with elastic band coupling for controlled force application
    \item \textbf{Device Under Test (DUT) mount:} 3D-printed holder brackets for single or dual servo configurations
    \item \textbf{Lever arms:} 100mm test levers for force transmission
    \item \textbf{Control software:} Node.js application for automated test sequencing and telemetry logging
    \item \textbf{Analysis software:} Python scripts for data visualization and backlash calculation
\end{enumerate}

All design files, test-controller software, and analysis scripts are openly available, allowing others to reproduce, adapt, or extend the system (see Sections~\ref{sec:design-files} and~\ref{sec:bom}).

By providing predictable loading and repeatable motion, the test stand offers a practical and accessible way to study backlash and evaluate performance improvements in low-cost UART servos.

\subsection{Comparison with Existing Methods}

\begin{table}[H]
\centering
\caption{Comparison of backlash measurement approaches.}
\label{tab:comparison}
\small
\begin{tabular}{lllll}
\toprule
\textbf{Method} & \textbf{Cost} & \textbf{Resolution} & \textbf{Probe Force} & \textbf{Automation} \\
\midrule
\multicolumn{5}{l}{\textit{Industrial gear measurement systems}} \\
\quad Klingelnberg P26 (used) \cite{klingelnberg_p26} & \$3,500+ & $<$\SI{0.01}{\degree} & None & Full \\
\quad Gleason GMS series \cite{gleason_gms} & \$20,000+ & $<$\SI{0.01}{\degree} & None & Full \\
\quad Mahr gear measuring (used) \cite{mahr_mx4} & \$22,000+ & $<$\SI{0.01}{\degree} & None & Full \\
\midrule
\multicolumn{5}{l}{\textit{Double-flank gear rolling testers}} \\
\quad Manual gear roll tester \cite{gear_roll_ebay} & \$750--2,150 & \SI{1}{\micro\meter}\textsuperscript{a} & None & None \\
\quad Motorized gear roll tester \cite{kudale_gear_tester} & \$16,000+ & \SI{1}{\micro\meter}\textsuperscript{a} & None & Full \\
\midrule
\multicolumn{5}{l}{\textit{Dial indicator methods}} \\
\quad Mitutoyo 513-series \cite{mitutoyo_513} & \$50--150 & \SI{0.01}{\milli\meter} & 0.2--0.4N & None \\
\quad Mitutoyo 3414S \cite{mitutoyo_3414s} & \$80--200 & \SI{0.01}{\milli\meter} & 1.8N max & None \\
\midrule
\textbf{This work} & \$80--100 & \SI{0.09}{\degree}\textsuperscript{b} & \textbf{None} & Full \\
\bottomrule
\end{tabular}
\vspace{0.5em}

\footnotesize{\textsuperscript{a}Linear resolution; angular resolution depends on gear geometry. \textsuperscript{b}Limited by servo encoder resolution (12-bit, 4096 counts/rev).}
\end{table}

A summary of how the proposed stand compares with existing industrial and dial-indicator approaches is given in Table~\ref{tab:comparison}.

%==============================================================================
\section{Hardware Description}
\label{sec:hardware-description}
%==============================================================================

The test stand is designed to be simple, modular, and easy to reproduce. It can be configured to test either a single servo motor or two mechanically coupled servos. The mechanical system consists of a base plate, servo holders, 100 mm bracket levers, puller motors, the motor or motors under test, and elastic bands that provide a soft loading mechanism.

\begin{figure}[ht]
    \centering
    
    \caption{Test stand setup for testing two servos coupled via common bracket lever}
    \label{fig:teststand}
\end{figure}

An overview of the complete mechanical setup is shown in Figure~\ref{fig:teststand}.

\subsection{Mechanical Structure}
\label{subsec:mechanical-structure}

\subsubsection{Base Plate}
\label{subsubsec:base-plate}

The base plate serves as the foundation of the stand. It is a flat, rigid surface without any predefined mounting patterns. Components are attached using clamps or fasteners, depending on the material and the required rigidity. This approach keeps the design flexible and allows users to adapt the layout to different test configurations. Materials such as acrylic, plywood, aluminum, or 3D-printed panels can all be used successfully.

\subsubsection{Motor Holders}
\label{subsubsec:motor-holders}

Motor holders are 3D-printed brackets used to secure the tested servo or servo pair. Two variants are available:

\begin{itemize}
    \item Single-motor holder for testing one servo.
    \item Dual-motor holder for evaluating two servos coupled together.
\end{itemize}

\begin{figure}[ht]
    \centering
    
    \caption{Two STS3215 servos mounted in the holder}
    \label{fig:servo_holder_x2}
\end{figure}

Each holder keeps the servo body fixed in place while maintaining alignment with the puller motors and the force-application mechanism. The holders are designed for easy installation on the base plate using clamps or screws; an example dual-motor holder is shown in Figure~\ref{fig:servo_holder_x2}.

\subsubsection{100 mm Bracket Levers}
\label{subsubsec:bracket-levers}

All servos in the stand—tested motors and puller motors—use 100 mm bracket levers. These levers attach to standard 25T servo horns mounted on both sides of the servo output shaft. Versions of the lever are provided for both single-servo and dual-servo configurations.

\begin{figure}[ht]
    \centering
    
    \caption{Two STS3215 servos coupled via common bracket lever}
    \label{fig:bracket_lever_x2}
\end{figure}

The lever length of 100 mm provides sufficient motion amplification for measuring small deviations while keeping the applied torque within controllable limits. The levers are typically 3D-printed, but any sufficiently rigid material may be used. A dual-servo lever configuration is illustrated in Figure~\ref{fig:bracket_lever_x2}.

\FloatBarrier

\subsubsection{Puller motors}
\label{subsubsec:puller-motors}

Two puller motors apply controlled external forces to the tested motor or motors. These motors may be Feetech or Waveshare UART servos, and they are mounted in simple 3D-printed holders on the base plate. Each puller motor is fitted with its own 100 mm lever, aligned so that force can be applied cleanly to the lever of the tested servo.

The puller motors do not participate in measurement. Their primary role is to generate repeatable clockwise and counter-clockwise loading during the test sequence. However, their position data is still logged and later used by the analysis software to determine the active phase of the test (preload, loaded, or unloaded) and to correctly classify samples for backlash estimation.

\subsubsection{Tested Motor(s)}
\label{subsubsec:tested-motors}

The center of the stand holds either one tested servo or a pair of coupled servos. The tested servo(s) are mounted in the corresponding single- or dual-motor holder and fitted with a 100 mm lever. This lever serves  as the force-application point.

Testing two coupled motors allows investigation of preload strategies, torque-sharing behavior, and the effects of coupling on backlash.

\begin{figure}[ht]
    \centering
    
    \caption{Example test setup. The center motor is holding its position, while the left motor is pulling the lever. At the same time, the right pulling motor is relaxed and does not apply any force.}
    \label{fig:test_setup}
\end{figure}

An example test configuration with one tested motor and two puller motors is shown in Figure~\ref{fig:test_setup}.

\FloatBarrier

\subsubsection{Elastic Bands for Soft Coupling}
\label{subsubsec:elastic-bands}

Elastic bands provide a soft and backlash-free connection between the puller motors and the tested motor lever. In the neutral position, the bands are almost fully relaxed. The puller motors rotate to a predefined angle to tension the bands and apply the desired force during the test.

Using elastic bands as the coupling element prevents additional mechanical backlash from being introduced into the system and smooths transitions when the load direction changes. The applied force is calibrated before testing by measuring the pull at the lever tip, allowing different force levels to be used depending on whether a single motor or a coupled pair is being evaluated.

\subsection{Electrical Integration}
\label{subsec:electrical}

The electrical system of the test stand is based on a simple UART daisy-chain network shared by all servos on the platform. This keeps wiring minimal and makes it easy to add or remove motors depending on whether a single-servo or dual-servo test configuration is being used.

\subsubsection{Daisy-Chain Servo Bus}
\label{subsubsec:daisy-chain}

All servos—puller motors and the tested motor or motors—are connected in a daisy-chain manner using their UART ports. This creates a single shared communication bus with only three required lines:

\begin{itemize}
    \item VCC (typically 7.4 or 12 V, depending on servo model)
    \item GND
    \item UART signal (half-duplex, TTL-level)
\end{itemize}

This wiring style allows multiple servos to receive commands and report telemetry over the same physical link. Each servo uses a unique ID, making it possible to address and read them individually.

\begin{figure}[ht]
    \centering
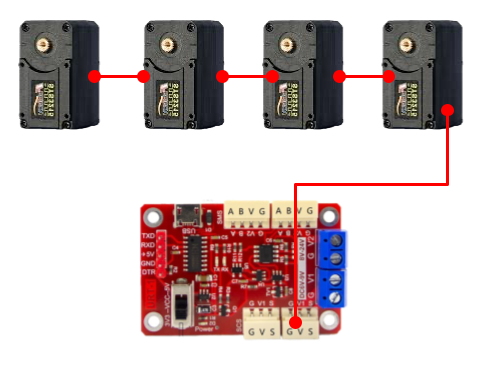
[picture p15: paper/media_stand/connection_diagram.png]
    
    \caption{Typical connection of 4 UART servos to USB-TTL board}
    \label{fig:connection_diagram}
\end{figure}

A typical wiring scheme for four servos connected to a USB–TTL interface is illustrated in Figure~\ref{fig:connection_diagram}.

\subsubsection{Power Delivery}
\label{subsubsec:power}

The stand can be powered by a standard DC supply appropriate for the selected servo models (commonly 7.4 or 12 V for Feetech units). All servos draw from the same power rails, so the supply should be sized to handle peak current from the puller motors during load application as well as the tested motor.

\subsubsection{USB-to-TTL Interface}
\label{subsubsec:usb-ttl}

A Feetech or Waveshare USB-to-TTL adapter connects the daisy-chain bus to the host computer. The adapter presents a virtual serial port, allowing the test controller software to:

\begin{itemize}
    \item send position commands to each servo
    \item read periodic telemetry
    \item synchronize puller motor movements with the measurement sequence
\end{itemize}

The adapter typically supports 1 Mbps communication, which is sufficient for streaming telemetry from several servos while issuing commands during the test.

\FloatBarrier

\subsubsection{Host Controller}
\label{subsubsec:host-controller}

A PC, laptop, or single-board computer (e.g., Raspberry Pi) runs the test controller software. It is responsible for:

\begin{itemize}
    \item coordinating puller-motor actuation
    \item executing preload and force-application sequences
    \item recording telemetry
\end{itemize}

This simple electrical architecture keeps the system compact while allowing full control over all motors and reliable acquisition of test data.

\subsection{Software}
\label{subsec:software}

The software stack coordinates the full test workflow: it drives the servos, manages the motion sequence, records telemetry, and provides tools for analysis and visualization. The system is intentionally lightweight and runs on a standard PC or single-board computer through a simple USB-to-TTL connection. All components are open source and designed for easy modification.

\subsubsection{Test Controller}
\label{subsubsec:test-controller}

The test controller is a Node.js application that communicates with all servos over the shared UART bus and executes the predefined motion sequence. Its main responsibilities include:

\begin{itemize}
    \item Test sequencing – Running the preload motion, applying calibrated tension through the puller motors, alternating between clockwise and counter-clockwise pulls, and relaxing the load between phases.
    \item Synchronized control – Ensuring all motors execute their portion of the sequence in a coordinated and repeatable manner.
    \item Telemetry logging – Continuously collecting status data from each servo during the full test cycle.
\end{itemize}

The controller is modular, making it straightforward to adjust timing, introduce new test routines, or experiment with alternative loading strategies. Further operational details are provided in Section~\ref{sec:operation}.

\subsubsection{Telemetry Logging}
\label{subsubsec:telemetry}

During operation, each servo reports its state at regular intervals. The controller collects these packets and stores them in CSV format. Typical fields include:

\begin{itemize}
    \item Timestamp
    \item Servo ID
    \item Target (commanded) position
    \item Actual encoder position
    \item Estimated load/torque
    \item Motor current
    \item Supply voltage
\end{itemize}

The default logging rate is around 10 Hz but can be increased or decreased depending on test conditions. These data form the basis for quantifying backlash, tracking positional deviations, and evaluating servo behavior under varying loads.

\subsubsection{Analysis Tools}
\label{subsubsec:analysis-tools}

A Python script is provided for processing and interpreting the recorded telemetry. Its core functions include:

\begin{itemize}
    \item Phase detection – Using puller-motor positions to identify preload, loaded, and unloaded intervals.
    \item Position-deviation analysis – Comparing target and actual positions under different loading conditions.
    \item Backlash estimation – Extracting CW and CCW reference points to compute effective backlash.
    \item Averaging and statistics – Aggregating multiple cycles to obtain stable, repeatable measurements.
\end{itemize}

The output includes numerical summaries and intermediate datasets suitable for further study or comparison across servos and parameter settings, as used in Section~\ref{sec:validation}.

\subsubsection{Visualization Tools}
\label{subsubsec:visualization-tools}

A dedicated visualization script converts processed data into clear, publication-ready charts. It produces plots such as:

\begin{itemize}
    \item Encoder position vs time
    \item Target position vs time
    \item Highlighted loaded and unloaded phases
\end{itemize}

These visualizations make it easier to interpret servo behavior, observe how different configurations influence performance, and communicate results effectively.

\newpage
%==============================================================================
\section{Design Files Summary}
\label{sec:design-files}
%==============================================================================
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

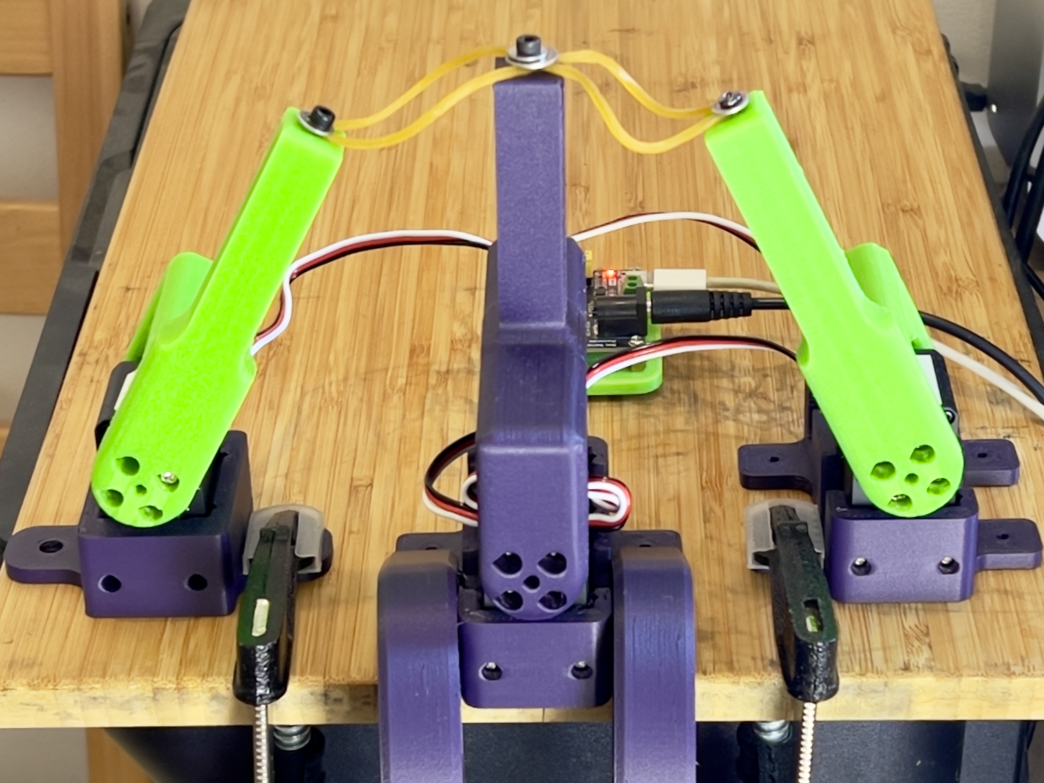
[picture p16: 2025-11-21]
paper/media_stand/teststand_1.jpg

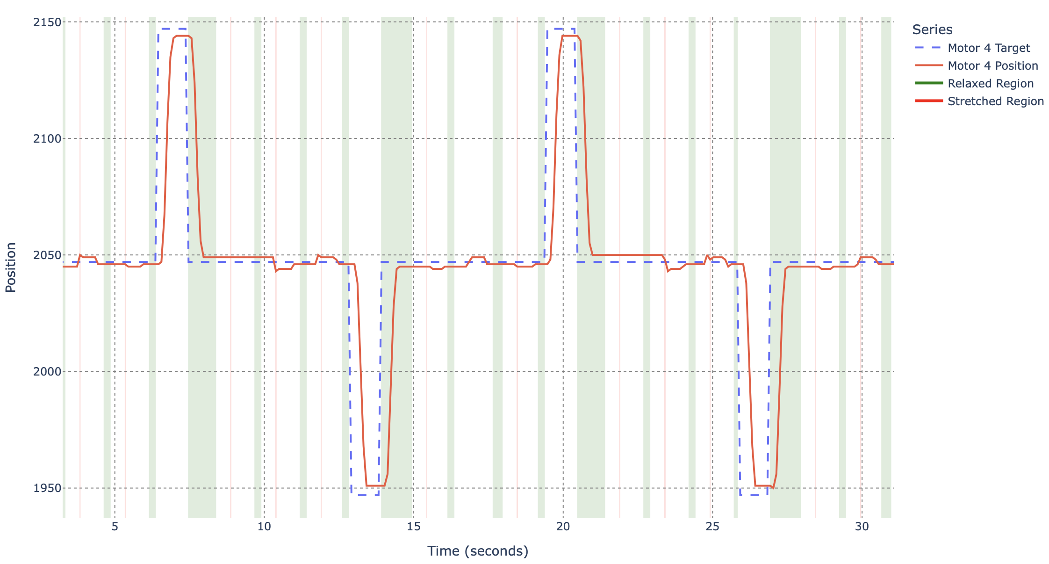
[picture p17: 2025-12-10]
paper/media_stand/test_results_single_STS3250.png

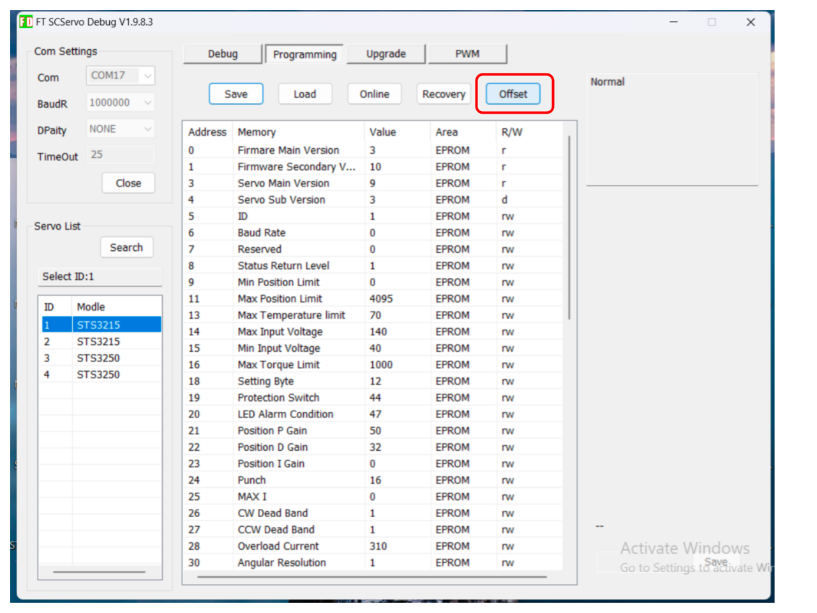
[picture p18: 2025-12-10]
paper/media_stand/calibration.png

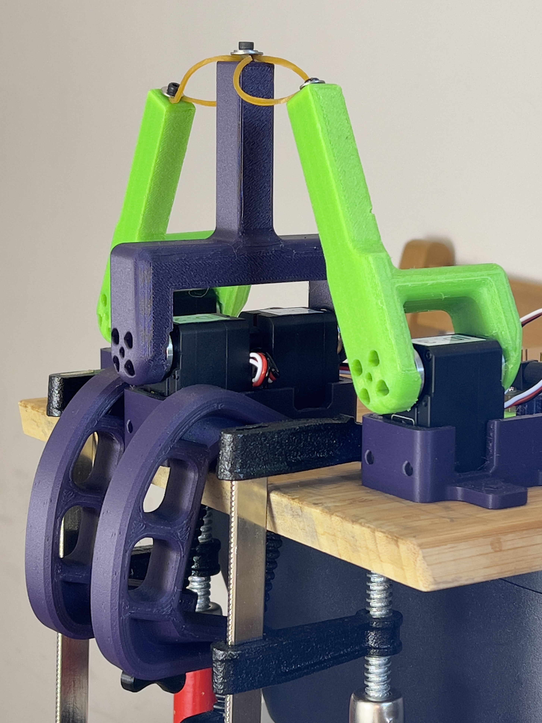
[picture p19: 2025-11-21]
paper/media_stand/teststand_2.jpg

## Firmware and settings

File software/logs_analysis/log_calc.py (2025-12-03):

#!/usr/bin/env python3
import os
import sys
from itertools import combinations
from typing import Dict, List, Optional

import numpy as np
import pandas as pd

from config_utils import (
    AnalysisConfig,
    MotorConfig,
    build_phase_mask,
    build_relaxed_mask,
    build_stretch_mask,
    ensure_columns,
    find_segments,
    load_config,
    pos_col,
    target_col,
)


def summarize_measurements(seg_slice: pd.DataFrame, report_motor_ids: List[int]) -> str:
    summaries = []
    for motor_id in report_motor_ids:
        avg = seg_slice[pos_col(motor_id)].mean()
        summaries.append(f"M{motor_id}_avg={avg:.2f}")
    return ", ".join(summaries)


def print_subsegment(label: str, seg_slice: pd.DataFrame, report_motor_ids: List[int]) -> None:
    t_start = seg_slice["t_sec"].iloc[0]
    t_end = seg_slice["t_sec"].iloc[-1]
    n_samples = len(seg_slice)
    measurements = summarize_measurements(seg_slice, report_motor_ids)
    print(
        f"    - {label}: samples={n_samples}, "
        f"t_sec=[{t_start:.3f}, {t_end:.3f}], {measurements}"
    )


def average_positions(slices: List[pd.DataFrame], report_motor_ids: List[int]) -> Optional[Dict[int, float]]:
    if not slices:
        return None
    concat = pd.concat(slices)
    return {motor_id: concat[pos_col(motor_id)].mean() for motor_id in report_motor_ids}


def analyze_log(df: pd.DataFrame, config: AnalysisConfig) -> None:
    required_columns = set()
    for motor_id in config.home_motor_ids:
        required_columns.add(target_col(motor_id))
        required_columns.add(pos_col(motor_id))
    for motor_id in config.report_motor_ids:
        required_columns.add(pos_col(motor_id))
    for motor in config.actuated_motors:
        required_columns.add(target_col(motor.motor_id))
        required_columns.add(pos_col(motor.motor_id))
    ensure_columns(df, sorted(required_columns))

    if "timestamp" in df.columns:
        try:
            df["timestamp"] = pd.to_datetime(df["timestamp"])
        except Exception:
            pass

    if "timestamp" in df.columns and pd.api.types.is_datetime64_any_dtype(df["timestamp"]):
        df["t_sec"] = (df["timestamp"] - df["timestamp"].iloc[0]).dt.total_seconds()
    else:
        df["t_sec"] = np.arange(len(df), dtype=float)

    phase_mask = build_phase_mask(df, config)
    raw_segments = find_segments(phase_mask)
    segments = [
        (start_idx, end_idx)
        for (start_idx, end_idx) in raw_segments
        if (end_idx - start_idx + 1) >= config.min_segment_samples
    ]

    if not segments:
        print("No phase-2 segments detected (check config thresholds).")
        return

    relaxed_mask = build_relaxed_mask(df, config.actuated_motors)
    stretch_masks = {motor.motor_id: build_stretch_mask(df, motor) for motor in config.actuated_motors}
    global_groups: Dict[str, Dict[str, List[pd.DataFrame]]] = {
        motor.label: {"stretched": [], "relaxed": []} for motor in config.actuated_motors
    }

    print("Detected phase-2 segments:")
    for seg_id, (start_idx, end_idx) in enumerate(segments, start=1):
        seg = df.iloc[start_idx:end_idx + 1]
        t_start = seg["t_sec"].iloc[0]
        t_end = seg["t_sec"].iloc[-1]
        n_samples = len(seg)
        print(f"  Segment {seg_id}: samples={n_samples}, t_sec=[{t_start:.3f}, {t_end:.3f}]")

        relaxed_local = relaxed_mask.iloc[start_idx:end_idx + 1].reset_index(drop=True)
        relaxed_segments = find_segments(relaxed_local)

        subsegments: List[tuple] = []
        for motor in config.actuated_motors:
            stretch_local = stretch_masks[motor.motor_id].iloc[start_idx:end_idx + 1].reset_index(drop=True)
            stretch_segments = find_segments(stretch_local)

            for ls, le in stretch_segments:
                global_start = start_idx + ls
                global_end = start_idx + le
                stretch_slice = df.iloc[global_start:global_end + 1]
                label = f"{motor.label} stretched"
                subsegments.append((label, stretch_slice))
                global_groups[motor.label]["stretched"].append(stretch_slice)

                for rs, re in relaxed_segments:
                    if rs > le:
                        r_start = start_idx + rs
                        r_end = start_idx + re
                        relaxed_slice = df.iloc[r_start:r_end + 1]
                        subsegments.append((f"{motor.label} relaxed", relaxed_slice))
                        global_groups[motor.label]["relaxed"].append(relaxed_slice)
                        break

        subsegments.sort(key=lambda item: item[1]["t_sec"].iloc[0])
        for label, seg_slice in subsegments:
            print_subsegment(label, seg_slice, config.report_motor_ids)

    print("\nTotal averages across all segments:")
    avg_cache: Dict[tuple, Optional[Dict[int, float]]] = {}
    for motor in config.actuated_motors:
        for state in ("stretched", "relaxed"):
            groups = global_groups[motor.label][state]
            avg_map = average_positions(groups, config.report_motor_ids)
            avg_cache[(motor.label, state)] = avg_map
            label = f"{motor.label} {state}"
            if avg_map is None:
                print(f"  {label}: no samples")
            else:
                metrics = ", ".join(f"M{mid}_avg={avg:.2f}" for mid, avg in avg_map.items())
                print(f"  {label}: {metrics}")

    print("\nPosition deviation:")
    motor_pairs = list(combinations(config.actuated_motors, 2))
    if not motor_pairs:
        print("  Requires at least two actuated motors.")
    else:
        for state in ("stretched", "relaxed"):
            for m1, m2 in motor_pairs:
                avg1 = avg_cache.get((m1.label, state))
                avg2 = avg_cache.get((m2.label, state))
                if not avg1 or not avg2:
                    print(f"  {state.title()} ({m1.label} vs {m2.label}): insufficient data")
                    continue
                diffs = [
                    f"M{mid}_dev={abs(avg1[mid] - avg2[mid]):.2f}"
                    for mid in config.report_motor_ids
                ]
                diff_text = ", ".join(diffs)
                print(f"  {state.title()} ({m1.label} vs {m2.label}): {diff_text}")

    print("Done.")


def main() -> None:
    if len(sys.argv) != 3:
        print("Usage: python log_calc.py <config.json> <path_to_csv>")
        sys.exit(1)

    config_path, csv_path = sys.argv[1], sys.argv[2]

    try:
        config = load_config(config_path)
    except (OSError, ValueError) as exc:
        print(f"Error loading config: {exc}")
        sys.exit(1)

    if not os.path.exists(csv_path):
        print(f"Error: Path does not exist: {csv_path}")
        sys.exit(1)
    if not os.path.isfile(csv_path):
        print(f"Error: Not a file: {csv_path}")
        sys.exit(1)

    try:
        df = pd.read_csv(csv_path)
    except Exception as exc:
        print(f"Error reading CSV: {exc}")
        sys.exit(1)

    try:
        analyze_log(df, config)
    except KeyError as exc:
        print(f"Error: {exc}")
        sys.exit(1)


if __name__ == "__main__":
    main()

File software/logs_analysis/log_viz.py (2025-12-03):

#!/usr/bin/env python3
import os
import sys
from typing import Dict, List

import numpy as np
import pandas as pd
import plotly.graph_objects as go

from config_utils import (
    AnalysisConfig,
    build_phase_mask,
    build_relaxed_mask,
    build_stretch_mask,
    ensure_columns,
    find_segments,
    load_config,
    pos_col,
    target_col,
)

SHOW_OUTLINES = True


def invert(series: pd.Series, home: float) -> pd.Series:
    """Mirror position value around home (e.g., 2247 ↔ 1847)."""
    return 2 * home - series


def add_interval_shapes(fig: go.Figure, df: pd.DataFrame, mask: pd.Series, color: str, y0: float, y1: float) -> None:
    """Add rectangular outlines for contiguous mask intervals."""
    segments = find_segments(mask)
    for start_idx, end_idx in segments:
        fig.add_shape(
            type="rect",
            x0=df["t_sec"].iloc[start_idx],
            x1=df["t_sec"].iloc[end_idx],
            y0=y0,
            y1=y1,
            fillcolor=color,
            opacity=0.15,
            line=dict(color=color, width=1),
            layer="below",
        )


def build_required_columns(config: AnalysisConfig) -> List[str]:
    cols = set()
    for motor_id in config.home_motor_ids:
        cols.add(target_col(motor_id))
        cols.add(pos_col(motor_id))
    for motor_id in config.report_motor_ids:
        cols.add(target_col(motor_id))
        cols.add(pos_col(motor_id))
    for motor in config.actuated_motors:
        cols.add(target_col(motor.motor_id))
        cols.add(pos_col(motor.motor_id))
    return sorted(cols)


def compute_outline_bounds(df: pd.DataFrame, config: AnalysisConfig) -> Dict[str, float]:
    columns = [pos_col(mid) for mid in config.report_motor_ids] + [target_col(mid) for mid in config.report_motor_ids]
    columns = [col for col in columns if col in df.columns]
    if not columns:
        return {"y_min": 0.0, "y_max": 1.0}
    y_min = df[columns].min().min()
    y_max = df[columns].max().max()
    if not np.isfinite(y_min) or not np.isfinite(y_max):
        y_min, y_max = 0.0, 1.0
    if y_min == y_max:
        y_min -= 1
        y_max += 1
    padding = 0.05 * (y_max - y_min)
    return {"y_min": y_min - padding, "y_max": y_max + padding}


def add_motor_traces(fig: go.Figure, df: pd.DataFrame, config: AnalysisConfig) -> None:
    mirror_second_motor = len(config.report_motor_ids) == 2
    mirrored_id = config.report_motor_ids[1] if mirror_second_motor else None

    for idx, motor_id in enumerate(config.report_motor_ids):
        motor_name = f"Motor {motor_id}"
        target = df[target_col(motor_id)]
        position = df[pos_col(motor_id)]
        mirrored = mirrored_id is not None and motor_id == mirrored_id
        if mirrored:
            target = invert(target, config.home_position)
            position = invert(position, config.home_position)
            motor_name += " (mirrored)"

        fig.add_trace(go.Scatter(
            x=df["t_sec"],
            y=target,
            mode="lines",
            name=f"{motor_name} Target",
            line=dict(dash="dash"),
        ))

        fig.add_trace(go.Scatter(
            x=df["t_sec"],
            y=position,
            mode="lines",
            name=f"{motor_name} Position",
            line=dict(dash="solid"),
        ))


def main() -> None:
    if len(sys.argv) != 3:
        print("Usage: python log_viz.py <config.json> <path_to_csv>")
        sys.exit(1)

    config_path, csv_path = sys.argv[1], sys.argv[2]

    try:
        config = load_config(config_path)
    except (OSError, ValueError) as exc:
        print(f"Error loading config: {exc}")
        sys.exit(1)

    if not os.path.exists(csv_path):
        print(f"Error: Path does not exist: {csv_path}")
        sys.exit(1)
    if not os.path.isfile(csv_path):
        print(f"Error: Not a file: {csv_path}")
        sys.exit(1)

    df = pd.read_csv(csv_path)

    try:
        df["timestamp"] = pd.to_datetime(df["timestamp"])
    except Exception:
        pass

    if "timestamp" in df.columns and pd.api.types.is_datetime64_any_dtype(df["timestamp"]):
        df["t_sec"] = (df["timestamp"] - df["timestamp"].iloc[0]).dt.total_seconds()
    else:
        df["t_sec"] = np.arange(len(df), dtype=float)

    try:
        ensure_columns(df, build_required_columns(config))
    except KeyError as exc:
        print(f"Error: {exc}")
        sys.exit(1)

    outline_bounds = compute_outline_bounds(df, config)
    phase_mask = build_phase_mask(df, config)
    relaxed_mask = build_relaxed_mask(df, config.actuated_motors) & phase_mask
    stretched_mask = pd.Series(False, index=df.index, dtype=bool)
    for motor in config.actuated_motors:
        stretched_mask |= build_stretch_mask(df, motor)

    fig = go.Figure()
    add_motor_traces(fig, df, config)

    if SHOW_OUTLINES:
        fig.add_trace(go.Scatter(x=[None], y=[None], mode="lines", line=dict(color="green", width=3), name="Relaxed Region"))
        fig.add_trace(go.Scatter(x=[None], y=[None], mode="lines", line=dict(color="red", width=3), name="Stretched Region"))
        add_interval_shapes(fig, df, relaxed_mask, "green", outline_bounds["y_min"], outline_bounds["y_max"])
        add_interval_shapes(fig, df, stretched_mask, "red", outline_bounds["y_min"], outline_bounds["y_max"])

    fig.update_layout(
        title="Motor targets vs positions",
        xaxis_title="Time (seconds)",
        yaxis_title="Position",
        hovermode="x unified",
        legend_title_text="Series",
        plot_bgcolor="#ffffff",
    )

    fig.update_xaxes(showgrid=True, gridcolor="gray", gridwidth=1, griddash="dot")
    fig.update_yaxes(showgrid=True, gridcolor="gray", gridwidth=1, griddash="dot")
    fig.show()


if __name__ == "__main__":
    main()

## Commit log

2025-11-21 feat: Add paper on Backlash Compensation in STS3215 Servo Actuators with experimental results and analysis. Includes figures and detailed methodology for dual-motor configuration to minimize backlash.
2025-11-21 refactor: Replace test stand images with a single high-resolution image and adjust figure widths for consistency in the paper on Backlash Compensation in STS3215 Servo Actuators.
2025-11-21 style: Replace \url with \xurl for improved line breaking in the paper on Backlash Compensation in STS3215 Servo Actuators and streamline the presentation of the GitHub repository link in the appendi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
2025-11-21 refactor: Update bibliography format in the paper on Backlash Compensation in STS3215 Servo Actuators, transitioning to BibTeX for improved citation management.
2025-11-22 chore: Add \nocite{*} to main.tex to ensure all references are included in the bibliography for the paper on Backlash Compensation in STS3215 Servo Actuators.
2025-11-26 refactor: Update references in bibliography for STS3215 servo actuators, including new product specifications, user manuals, and software resources for improved citation accuracy and accessibility.
2025-11-28 Add cad files and move software files into software dir
    [servo_holder_dual.step, servo_holder_dual.stl, servo_holder_single.step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]
2025-12-10 Remove main article and submission checklist files as part of project restructuring. The focus is now on the dual-motor backlash compensation system for STS3215 servo actuators, enhancing clarity and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
